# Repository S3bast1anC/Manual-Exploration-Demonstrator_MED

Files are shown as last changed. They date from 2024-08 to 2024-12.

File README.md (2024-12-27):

# Manual-Exploration-Demonstrator_MED
The Manual Exploration Demonstrator (MED) is a rover developed to test hands-on exploration capabilities. Inspiration from Mechanical Sciences’ - [Design and analysis of a six-wheeled companion robot with mechanical obstacle-overcoming adaptivity](https://ms.copernicus.org/articles/12/1115/2021/). This repo provides an overview of MED's design, components, and operational guidelines to facilitate its use and maintenance.

<p align="center">
  
</p>

## About MED
### Motivation
The core design of MED revolves around a six-wheel rover with two independently rotating rear arms. This rover was created for the Mars Habitat at Berkeley (MHAB) software sub-team for autonomous code testing. The rover's modular design allows for future modifications, whether through hardware upgrades or software adjustments. Its six-wheel design allows  navigation across complex terrain, while the rotating rear provide additional mobility for overcoming obstacles.

We aim to share insights and lessons learned from the design, testing, and implementation of the MED rover. We hope that this information will not only assist the MHAB team but also inspire and guide future rover projects.

### Overview
<p align="center">
  
</p>

Development of MED began as part of the Final BLE Vehicle project for the UC Berkeley Summer 2024 DesInv22 class. Over the course of four weeks, myself and Andrew Alatorre engaged in a process of design, testing, iteration, and refinement to bring the rover to its current state.

<div align="center">
<table>
  <tr>
    <td>
      <table>
        <tr>
          <th>Specification</th>
          <th>Details</th>
        </tr>
        <tr>
          <td>Dimension (LxWxH)</td>
          <td>33.81cm x 22.4cm x 10.37cm</td>
        </tr>
        <tr>
          <td>Top Speed</td>
          <td> tbd m/s</td>
        </tr>
        <tr>
          <td>Total Mass</td>
          <td> tbd kg</td>
        </tr>
        <tr>
          <td>Wheel Diameter</td>
          <td> 6.9cm (front/rear), 8.61cm (back) </td>
        </tr>
        <tr>
          <td>Operational Range</td>
          <td> tbd </td>
        </tr>
        <tr>
          <td>Climbing Gradient</td>
          <td> tbd </td>
        </tr>
        <tr>
          <td>Cost</td>
          <td>$90.61</td>
        </tr>
      </table>
    </td>
    <td>
      <a href="https://youtu.be/sea0DLn0pgA" target="_blank">
    Watch the video
</a>
    </td>
  </tr>
</table>
</div>

## Components
### Features

<p align="center">
  
</p>

<ul>
  <li> <b> Six-Wheel Drive: </b> MED is built on a six-wheel drive system, providing improved traction and stability. This configuration ensures balanced weight distribution and allows the rover to handle rough, uneven surfaces with ease.</li>
  <li> <b> Freely Rotating Rear Arms: </b> The two rear arms are capable of rotating freely, giving the rover additional flexibility when navigating obstacles. These arms help stabilize the rover going over inclines and allow for obstacle-overcoming adaptivity in challenging environments.</li>
  <li> <b> Lightweight Build: </b> Constructed from PLA and acrylic, MED’s lightweight chassis allows for easy transportation and reduced energy consumption, while still offering a durable frame for the rover's internal electronics. It was designed this way as an ideal balance between durability and weight, enabling both indoor and outdoor testing.</li>
<li> <b>Rear Storage Compartment:</b> MED includes a simple rear storage compartment, serving as an early look at soil collection concepts. While still remaining simple in design so it can be changed easily." </li>
  
</ul>

### ELECTRONICS
- Arduino Uno Rev3 ([DIGIKEY](https://www.digikey.com/en/products/detail/arduino/A000066/2784006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)) ([DESC](https://store-usa.arduino.cc/products/arduino-uno-rev3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))
- Adafruit Motor Shield V2 ([DIGIKEY](https://www.digikey.com/en/products/detail/adafruit-industries-llc/1438/5353647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)) ([DESC](https://learn.adafruit.com/adafruit-motor-shield-v2-for-arduino/overview))
  - Bluefruit LE UART BT BLE ([DIGIKEY](https://www.digikey.com/en/products/detail/adafruit-industries-llc/2479/5356835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)) ([DESC](https://www.adafruit.com/product/2479))
  - Stacking Headers ([DIGIKEY](https://www.digikey.com/en/products/detail/adafruit-industries-llc/85/5154649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)) ([DESC](https://learn.adafruit.com/adafruit-motor-shield-v2-for-arduino/install-headers))
- 4 DC Gear Motor TT - 120 RPM ([DIGIKEY](https://www.digikey.com/en/products/detail/seeed-technology-co.,-ltd/114090050/10385087?utm_adgroup=&utm_source=google&utm_medium=cpc&utm_campaign=PMax%20Shopping_Product_Low%20ROAS%20Categories&utm_term=&utm_content=&utm_id=go_cmp-20243063506_adg-_ad-__dev-c_ext-_prd-10385087_sig-EAIaIQobChMI8M6mgs6GiAMVdxGtBh0vUSmqEAQYASABEgIGUPD_BwE&gad_source=1&gclid=EAIaIQobChMI8M6mgs6GiAMVdxGtBh0vUSmqEAQYASABEgIGUPD_BwE)) ([DESC](https://grobotronics.com/dc-gear-motor-tt-120-rpm-metal-shaft-blue.html?sl=en))
- 10 AA Batteries (4 for R3 board, 6 for DC motors) ([JACOBS](https://store.jacobshall.org/products/battery-aa?_pos=1&_sid=8ecd7b75d&_ss=r))

### Other Parts
- 3 Radial Ball Bearings (608ZZ) ([DIGIKEY](https://www.digikey.com/en/products/detail/adafruit-industries-llc/1178/5356858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))
- 2 4AA Battery Holder with On/Off Switch ([PARTSEXP](https://www.parts-express.com/4-AA-Battery-Holder-with-On-Off-Switch-140-784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))
- 1 2AA Battery Holder with On/Off Switch ([DIGIKEY](https://www.digikey.com/en/products/detail/sparkfun-electronics/PRT-09925/6161750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))
<p align="center">
  
</p>

### Notes
The V-in on the the adafruit motor shield was busted (i.e it wouldn't power the arduino which is an issue because that's what runs the code) so to solve this issue a 4 battery pack was soddered onto the bottom of the board to power it (it's a 5V board). Also the arduino is a limited edition [Maker Shed Exclusive](https://makezine.com/article/technology/arduino/maker-shed-exclusive-make-special-edition-arduino-unos/) uno board (no particular reason that's just what was lying around).

## Software
### Setup
The software for MED is designed to run on Arduino BLE software and communicates with the rover's motors and sensors via Bluetooth using the Ada_BLE_RC program. Ensure that the following three files are placed inside this folder:
1. Ada_BLE_RC.ino - This is the main Arduino sketch file that contains the code to control the rover.
2. BluefruitConfig.h - This header file includes configuration settings specific to the Adafruit Bluefruit BLE module, such as connection parameters and pin definitions.
3. packetParser.cpp - This C++ file handles the parsing of incoming data packets from the Bluetooth controller, translating them into motor control commands for the rover.

Once you have these files inside the Ada_BLE_RC folder, the entire folder should be uploaded to the Arduino IDE. To ensure the code runs correctly, you need to install the following libraries:
- Adafruit BluefruitLE nRF51 (Includes Adafruit_BLE, Adafruit_BluefruitLE_SPI, Adafruit_BluefruitLE_UART)
- SPI (Built-in with Arduino IDE)
- SoftwareSerial (Built-in with Arduino IDE)

*To change the rpm of the motors go to lines 302-305 (for example 'L_MOTOR1->setSpeed(##);' ).
### Bluetooth
The Bluefruit Connect app by Adafruit allows you to send commands to your rover via Bluetooth using a smartphone. Once the app is installed:
- Enable Bluetooth on your smartphone if it's not already on
- Open the Bluefruit Connect app
- Tap the "Connect" button within the app. It will scan for available Bluetooth devices
- Select your Bluefruit BLE module from the list of available devices (it may be named something like "Bluefruit52" or "UART")
- Once connected, you can access various control options within the app such as Control Pad, Accelerometer, or Color Picker to send commands to the rover


## Parameterized Design Model
This drawing presents the geometric parameter model of MED. The diagram highlights the rover's key coordinate frames, geometric parameters, and critical angles.

<p align="center">
  
</p>

Coordinate Frames:
- O: The global reference frame. This serves as the origin for measuring key lengths and angles for the system's kinematics.

Key Measurements:
- Width (W): Denotes the total width of the rover, measured from the outer edges of the wheels on the left and right sides.
- Length (L): Refers to the overall length of the rover, including the front and rear sections.
- Arm Radius (R): Represents the distance from the centroid of the arms at O<sub>2</sub> to the tip of the rocker arm wheels.
- Arm Wheel Radius (r<sub>0</sub>): Describes the radius of the arm wheels connected to the rocker arms.
- Rear Wheel radius (r<sub>1</sub>): Denotes the radius of the rear wheels of the rover.
  
Angles:
- θ<sub>r</sub>: The right arm swing angle, which defines the rotational displacement of the right rocker arm about its pivot point at O<sub>2</sub>.
- θ<sub>l</sub>: The left arm swing angle, representing the rotational displacement of the left rocker arm about its pivot point at O<sub>1</sub>.
- θ<sub>b</sub>: The rear body rotation angle, indicating the tilt or rotation of the rear section of the rover relative to the global reference frame.

The diagram shows the rover's geometric and kinematic structure, focusing on the relationship between the rocker-bogie arms, wheels, and the main body. The rover is shown with its front and rear sections positioned about the center of mass, labeled as C. The length of the rover, L, is measured between the front and rear wheels, while the width W is measured between the outermost points of the left and right wheels. The rocker arms pivot at origins O<sub>2</sub> and O<sub>1</sub>, and their rotation is described by the swing angles θ<sub>r</sub> and θ<sub>l</sub>. The rotation of the rear section is described by θ<sub>b</sub>. 

The radii R and r<sub>0</sub> describe the size and positioning of the rocker arm wheels, with R being the length from the rocker arm pivot point to the wheel, and r<sub>0</sub> and r<sub>1</sub> defining the sizes of the arm wheels and rear wheels, respectively.

<div align="center">
<table>
  <tr>
    <th>
      <p align="center">
        
      </p>
    </th>
    <th>
      <p align="center">
        
      </p>
    </th>
  </tr>
   <tr>
    <th>
      <p align="center">
        
      </p>
    </th>
    <th>
      <p align="center">
        
      </p>
    </th>
  </tr>
</table>
</div>

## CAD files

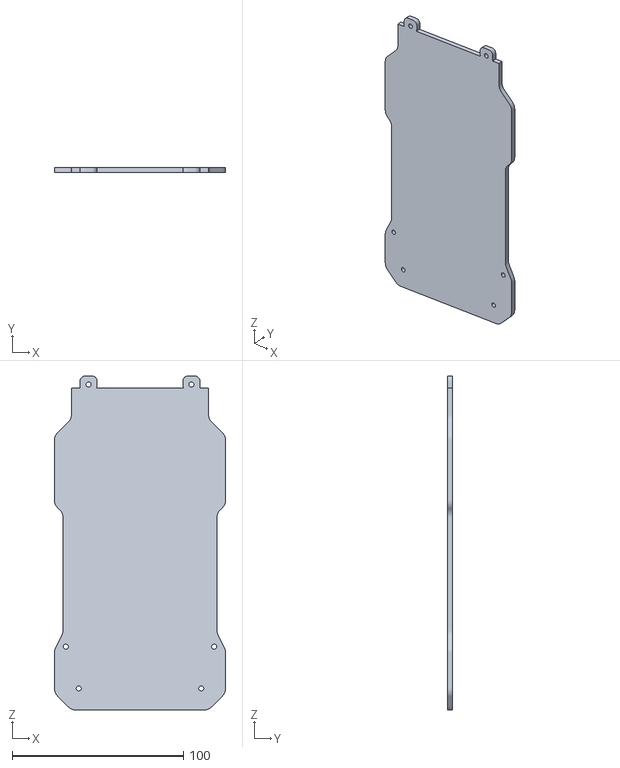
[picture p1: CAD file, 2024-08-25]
STL_Files/Acrylic_Main_Body.stl
100.0 x 3.17 x 195.0

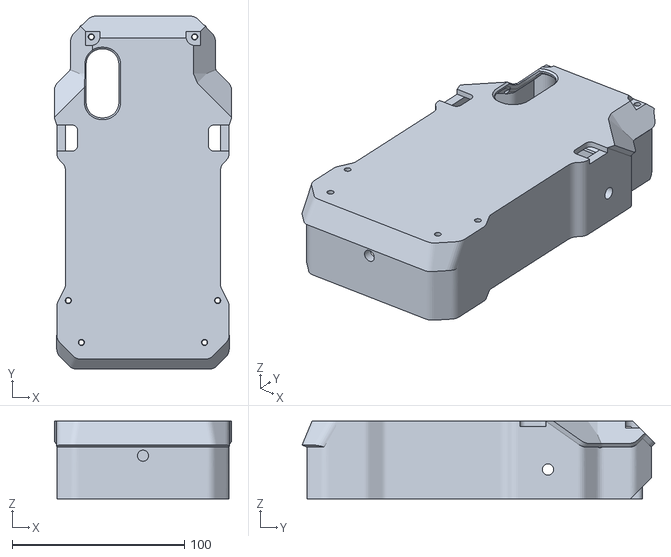
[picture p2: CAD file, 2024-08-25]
STL_Files/Main_Frame (and Lid).stl
103.0 x 204.9 x 45.0

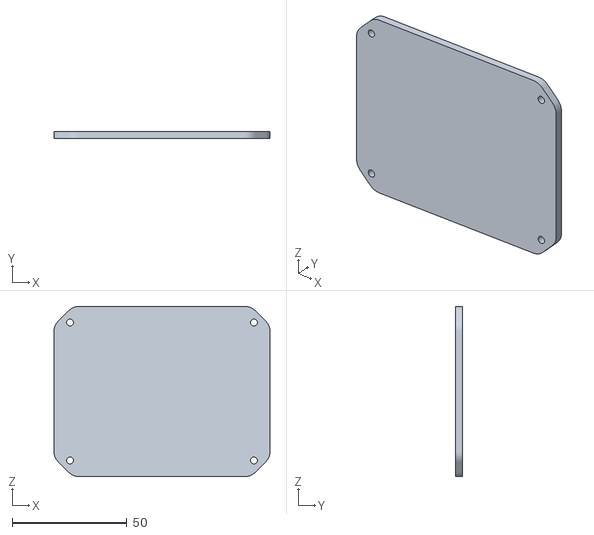
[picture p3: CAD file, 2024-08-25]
STL_Files/Acrylic_Rear_Body.stl
94.0 x 3.17 x 74.0

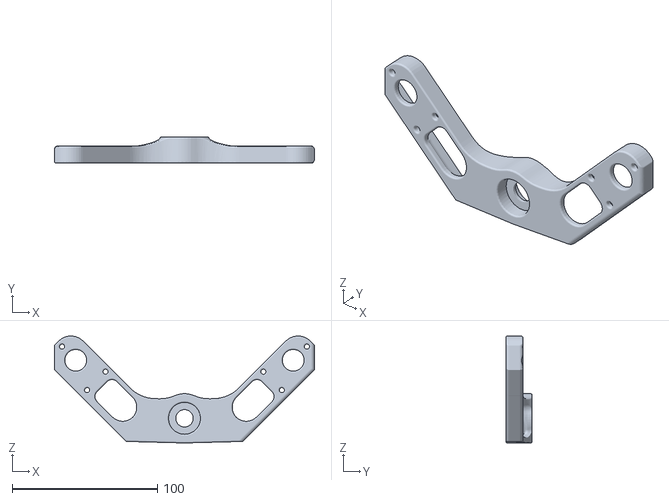
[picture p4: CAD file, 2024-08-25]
STL_Files/Wheel_Rocker_Arms.stl
179.3 x 18.0 x 73.7

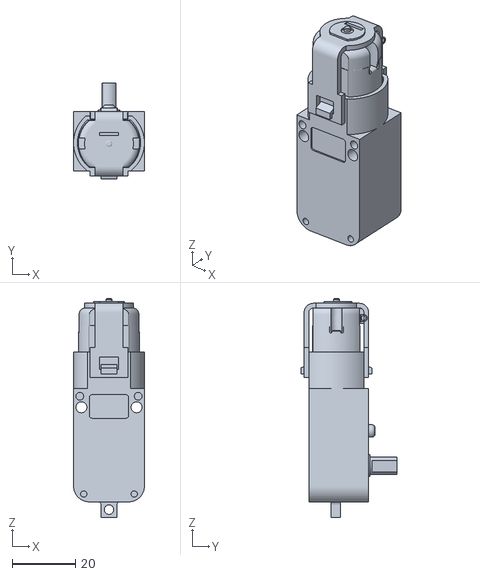
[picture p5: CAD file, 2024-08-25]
STL_Files/Geared_Motor_3-6V.stl
22.5 x 30.5 x 69.5

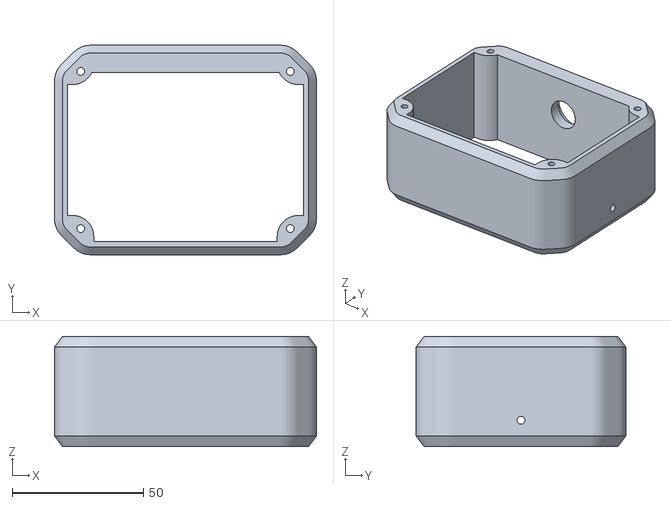
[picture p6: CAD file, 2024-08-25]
STL_Files/Back_Frame.stl
100.0 x 80.0 x 42.0

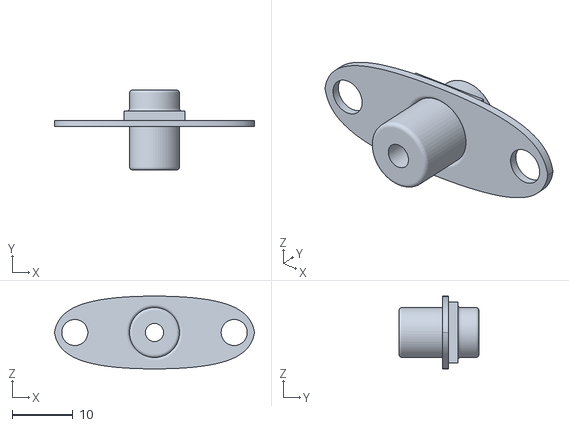
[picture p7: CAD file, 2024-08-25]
STL_Files/Wheel_Hub.stl
33.0 x 13.2 x 12.0

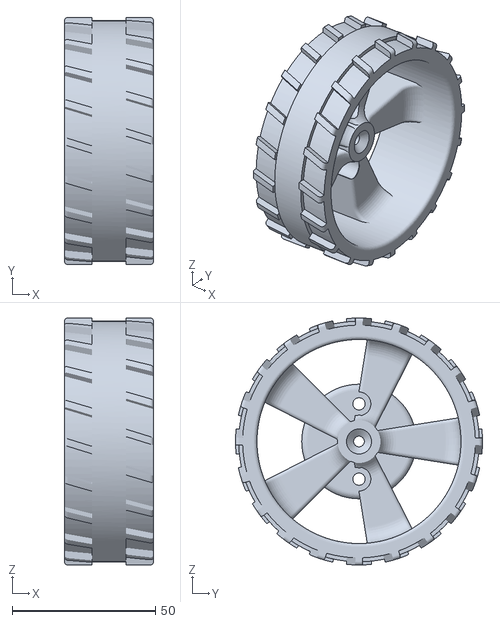
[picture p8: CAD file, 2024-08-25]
STL_Files/Wheel_1.25 (rubberband).stl
31.2 x 86.2 x 86.2

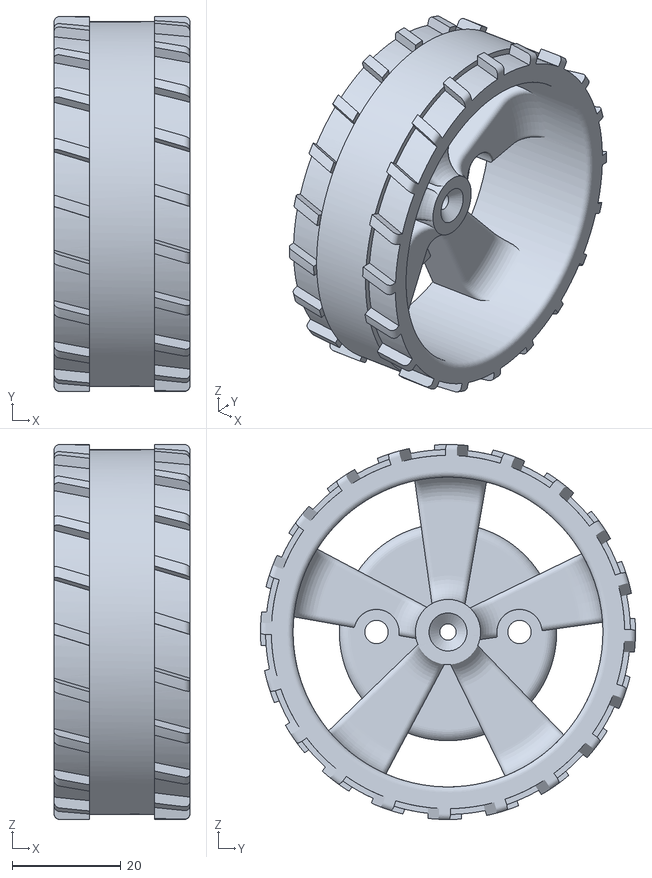
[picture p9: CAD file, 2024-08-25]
STL_Files/Wheel_1.00 (rubberband).stl
25.0 x 69.0 x 69.0

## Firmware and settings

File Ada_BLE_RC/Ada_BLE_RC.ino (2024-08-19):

// SPDX-FileCopyrightText: 2018 Limor Fried for Adafruit Industries
//
// SPDX-License-Identifier: MIT

/*********************************************************************
 This is an example for our nRF51822 based Bluefruit LE modules
  
 Modified to drive a 3-wheeled BLE Robot Rover! by http://james.devi.to
 Pick one up today in the Adafruit shop!
 Adafruit invests time and resources providing this open source code,
 please support Adafruit and open-source hardware by purchasing
 products from Adafruit!
 MIT license, check LICENSE for more information
 All text above, and the splash screen below must be included in
 any redistribution
*********************************************************************/

#include <string.h>
#include <Arduino.h>
#include <SPI.h>
#if not defined (_VARIANT_ARDUINO_DUE_X_)
  #include <SoftwareSerial.h>
#endif

#include "Adafruit_BLE.h"
#include "Adafruit_BluefruitLE_SPI.h"
#include "Adafruit_BluefruitLE_UART.h"

#include "BluefruitConfig.h"

#include <Wire.h>
#include <Adafruit_MotorShield.h>

#define Forward50 50
#define Forward100 100
// #include "utility/Adafruit_PWMServoDriver.h"
// #include <Servo.h> 

// Create the motor shield object with the default I2C address
Adafruit_MotorShield AFMS = Adafruit_MotorShield(); 

// And connect 2 DC motors to port M3 & M4 !
Adafruit_DCMotor *R_MOTOR1 = AFMS.getMotor(1);
Adafruit_DCMotor *R_MOTOR2 = AFMS.getMotor(2);
Adafruit_DCMotor *L_MOTOR1 = AFMS.getMotor(3);
Adafruit_DCMotor *L_MOTOR2 = AFMS.getMotor(4);

//not used, testing acceleration
// int accelTime = 200;

//Name your RC here
String BROADCAST_NAME = "adafruit red robot rover";

String BROADCAST_CMD = String("AT+GAPDEVNAME=" + BROADCAST_NAME);

Adafruit_BluefruitLE_SPI ble(BLUEFRUIT_SPI_CS, BLUEFRUIT_SPI_IRQ, BLUEFRUIT_SPI_RST);


// A small helper
void error(const __FlashStringHelper*err) {
  Serial.println(err);
  while (1);
}

// function prototypes over in packetparser.cpp
uint8_t readPacket(Adafruit_BLE *ble, uint16_t timeout);
float parsefloat(uint8_t *buffer);
void printHex(const uint8_t * data, const uint32_t numBytes);

// the packet buffer
extern uint8_t packetbuffer[];

char buf[60];

/**************************************************************************/
/*!
    @brief  Sets up the HW an the BLE module (this function is called
            automatically on startup)
*/
/**************************************************************************/
void setup(void)
{
  Serial.begin(9600);

  AFMS.begin();  // create with the default frequency 1.6KHz

  // turn on motors
  L_MOTOR1->setSpeed(0);
  L_MOTOR1->run(RELEASE);
  L_MOTOR2->setSpeed(0);
  L_MOTOR2->run(RELEASE);

  R_MOTOR1->setSpeed(0);
  R_MOTOR1->run(RELEASE);
  R_MOTOR2->setSpeed(0);
  R_MOTOR2->run(RELEASE);
    
  Serial.begin(115200);
  Serial.println(F("Adafruit Bluefruit Robot Controller Example"));
  Serial.println(F("-----------------------------------------"));

  /* Initialize the module */
  BLEsetup();
  

}

int velocity = 0;

float x, y;

int L_restrict = 0;
int R_restrict = 0;

unsigned long lastAccelPacket = 0;

bool modeToggle = false;

void loop(void)
{
    // read new packet data
    uint8_t len = readPacket(&ble, BLE_READPACKET_TIMEOUT);
    // if (len == 0) return;

  // Read from Accelerometer input
    if( accelMode() ) {
      lastAccelPacket = millis();
      modeToggle = true;
      return;
    }

  // Stop motors if accelerometer data is turned off (100ms timeout)
    if( millis() - lastAccelPacket > 100 & modeToggle) {
      L_MOTOR1->run(RELEASE);
      L_MOTOR2->run(RELEASE);
      R_MOTOR1->run(RELEASE);
      R_MOTOR2->run(RELEASE);
      modeToggle = false;
      return;
    }

    //if no accelerometer, use control pad
    if( !modeToggle ) buttonMode();
    
}


bool accelMode(){
  if (packetbuffer[1] == 'A') {
          x = parsefloat( packetbuffer + 2 );
          y = parsefloat( packetbuffer + 6 );

        if( x <= -0.55 ){
          x += 0.55;
          x *= -100.0;
          L_MOTOR1->run( BACKWARD );
          L_MOTOR2->run( BACKWARD );
          R_MOTOR1->run( BACKWARD );
          R_MOTOR2->run( BACKWARD );
          if( x >= 45 ) x = 45;
          if( x <= 0 ) x = 0;
          velocity = map( x, 0, 45, 0 ,255 );
        }
        else if( x >= -0.25 ){
          x+= 0.25;
          x *= 100;
          L_MOTOR1->run( FORWARD );
          L_MOTOR2->run( FORWARD );
          R_MOTOR1->run( FORWARD );
          R_MOTOR2->run( FORWARD );
          
          if( x>= 45 ) x = 45;
          if( x<= 0 ) x = 0;
          velocity = map( x, 0, 45, 0, 255 );
        }
        else{
          L_MOTOR1->run( RELEASE );
          L_MOTOR2->run( RELEASE );
          R_MOTOR1->run( RELEASE );
          R_MOTOR2->run( RELEASE );
          velocity = 0;
        }

        //account for L / R accel

        if( y >= 0.1 ){
            y -= 0.1;
            y *= 100;
            if( y >= 50 ) y = 50;
            if( y <= 0 ) y = 0;

            L_restrict = fscale( y, 0.0, 50.0, 0.0, 100.0, -4.0 );
        }
        else if( y <= -0.1 ){
            y += 0.1;
            y *= -100;
            if( y>= 50 ) y = 50;
            if( y<= 0 ) y = 0;

            R_restrict = fscale( y, 0.0, 50.0, 0.0, 100.0, -4.0 );
        }
        else{
            L_restrict = 0;
            R_restrict = 0;
        }

          float Lpercent = ( 100.0 - L_restrict ) / 100.00 ;
          float Rpercent = ( 100.0 - R_restrict ) / 100.00 ;

          // Serial.print( x ); 
          // Serial.print( "\t" ); 
          // Serial.print( Lpercent ); 
          // Serial.print( "\t" ); 
          // Serial.print( velocity ); 
          // Serial.print( "\t" ); 
          // Serial.println( Rpercent ); 

          L_MOTOR1->setSpeed( velocity * Lpercent ); 
          L_MOTOR2->setSpeed( velocity * Lpercent ); 
          R_MOTOR1->setSpeed( velocity * Rpercent ); 
          R_MOTOR2->setSpeed( velocity * Rpercent );
           

          return true;
    }
    return false;
}

bool isMoving = false;

bool buttonMode(){

  static unsigned long lastPress = 0;
  

 // Buttons
  if (packetbuffer[1] == 'B') {

    uint8_t buttnum = packetbuffer[2] - '0';
    boolean pressed = packetbuffer[3] - '0';

    // Serial.println(buttnum);

  Serial.println(isMoving);
    if (pressed) {
      isMoving = true;
      if(buttnum == 5){ //forward
        L_MOTOR1->run(FORWARD);
        L_MOTOR2->run(FORWARD);
        R_MOTOR1->run(FORWARD);
        R_MOTOR2->run(FORWARD);
      }
      if(buttnum == 6){ //backward
        L_MOTOR1->run(BACKWARD);
        L_MOTOR2->run(BACKWARD);
        R_MOTOR1->run(BACKWARD); 
        R_MOTOR2->run(BACKWARD);        
      }
      if(buttnum == 7){ //left
        L_MOTOR1->run(BACKWARD);
        L_MOTOR2->run(BACKWARD);
        R_MOTOR1->run(FORWARD);
        R_MOTOR2->run(FORWARD);
      }
      if(buttnum == 8){ //right
        L_MOTOR1->run(FORWARD);
        L_MOTOR2->run(FORWARD);
        R_MOTOR1->run(BACKWARD);        
        R_MOTOR2->run(BACKWARD);        
      }

      if(buttnum == 1){ //forward-left
        L_MOTOR1->run(Forward50);
        L_MOTOR2->run(Forward50);
        R_MOTOR1->run(FORWARD);        
        R_MOTOR2->run(FORWARD);     
      }

      if(buttnum == 2){ //forward-right
        L_MOTOR1->run(FORWARD);
        L_MOTOR2->run(FORWARD);
        R_MOTOR1->run(RELEASE);        
        R_MOTOR2->run(RELEASE);     
      }

      if(buttnum == 3){ //back-left
        L_MOTOR1->run(RELEASE);
        L_MOTOR2->run(RELEASE);
        R_MOTOR1->run(BACKWARD);        
        R_MOTOR2->run(BACKWARD);     
      }
      
      if(buttnum == 4){ //back-right
        L_MOTOR1->run(BACKWARD);
        L_MOTOR2->run(BACKWARD);
        R_MOTOR1->run(RELEASE);        
        R_MOTOR2->run(RELEASE);     
      }

      lastPress = millis();
      
        L_MOTOR1->setSpeed(230); 
        L_MOTOR2->setSpeed(230); 
        R_MOTOR1->setSpeed(230);  
        R_MOTOR2->setSpeed(230);  
    } 

    else {
      isMoving = false;
      L_MOTOR1->run(RELEASE);
      L_MOTOR2->run(RELEASE);
      R_MOTOR1->run(RELEASE);
      R_MOTOR2->run(RELEASE);
    }
     return true; 
  }
    // if(isMoving){
      
      // unsigned long timeSincePress = millis() - lastPress;

      // if(timeSincePress <= accelTime){

      //   Serial.println( timeSincePress ) ;
        
      //   int motorSpeed = map( timeSincePress, 0, accelTime, 0, 255 );
        
      //   L_MOTOR->setSpeed(motorSpeed); 
      //   R_MOTOR->setSpeed(motorSpeed); 
      // }
      
      // else{
       // // full speed ahead!
        // L_MOTOR->setSpeed(255); 
        // R_MOTOR->setSpeed(255);  
      // }
   // }

  return false;

}

void BLEsetup(){
  Serial.print(F("Initialising the Bluefruit LE module: "));

  if ( !ble.begin(VERBOSE_MODE) )
  {
    error(F("Couldn't find Bluefruit, make sure it's in CoMmanD mode & check wiring?"));
  }
  Serial.println( F("OK!") );

  /* Perform a factory reset to make sure everything is in a known state */
  Serial.println(F("Performing a factory reset: "));
  if (! ble.factoryReset() ){
       error(F("Couldn't factory reset"));
  }

  //Convert the name change command to a char array
  BROADCAST_CMD.toCharArray(buf, 60);

  //Change the broadcast device name here!
  if(ble.sendCommandCheckOK(buf)){
    Serial.println("name changed");
  }
  delay(250);

  //reset to take effect
  if(ble.sendCommandCheckOK("ATZ")){
    Serial.println("resetting");
  }
  delay(250);

  //Confirm name change
  ble.sendCommandCheckOK("AT+GAPDEVNAME");

  /* Disable command echo from Bluefruit */
  ble.echo(false);

  Serial.println("Requesting Bluefruit info:");
  /* Print Bluefruit information */
  ble.info();

  Serial.println(F("Please use Adafruit Bluefruit LE app to connect in Controller mode"));
  Serial.println(F("Then activate/use the sensors, color picker, game controller, etc!"));
  Serial.println();

  ble.verbose(false);  // debug info is a little annoying after this point!

  /* Wait for connection */
  while (! ble.isConnected()) {
      delay(500);
  }

  Serial.println(F("*****************"));

  // Set Bluefruit to DATA mode
  Serial.println( F("Switching to DATA mode!") );
  ble.setMode(BLUEFRUIT_MODE_DATA);

  Serial.println(F("*****************"));
}

//Logarithmic mapping function from http://playground.arduino.cc/Main/Fscale
float fscale( float inputValue,  float originalMin, float originalMax, float newBegin, float newEnd, float curve){

  float OriginalRange = 0;
  float NewRange = 0;
  float zeroRefCurVal = 0;
  float normalizedCurVal = 0;
  float rangedValue = 0;
  boolean invFlag = 0;


  // condition curve parameter
  // limit range

  if (curve > 10) curve = 10;
  if (curve < -10) curve = -10;

  curve = (curve * -.1) ; // - invert and scale - this seems more intuitive - postive numbers give more weight to high end on output 
  curve = pow(10, curve); // convert linear scale into lograthimic exponent for other pow function

  /*
   Serial.println(curve * 100, DEC);   // multply by 100 to preserve resolution  
   Serial.println(); 
   */

  // Check for out of range inputValues
  if (inputValue < originalMin) {
    inputValue = originalMin;
  }
  if (inputValue > originalMax) {
    inputValue = originalMax;
  }

  // Zero Refference the values
  OriginalRange = originalMax - originalMin;

  if (newEnd > newBegin){ 
    NewRange = newEnd - newBegin;
  }
  else
  {
    NewRange = newBegin - newEnd; 
    invFlag = 1;
  }

  zeroRefCurVal = inputValue - originalMin;
  normalizedCurVal  =  zeroRefCurVal / OriginalRange;   // normalize to 0 - 1 float

  /*
  Serial.print(OriginalRange, DEC);  
   Serial.print("   ");  
   Serial.print(NewRange, DEC);  
   Serial.print("   ");  
   Serial.println(zeroRefCurVal, DEC);  
   Serial.println();  
   */

  // Check for originalMin > originalMax  - the math for all other cases i.e. negative numbers seems to work out fine 
  if (originalMin > originalMax ) {
    return 0;
  }

  if (invFlag == 0){
    rangedValue =  (pow(normalizedCurVal, curve) * NewRange) + newBegin;

  }
  else     // invert the ranges
  {   
    rangedValue =  newBegin - (pow(normalizedCurVal, curve) * NewRange); 
  }

  return rangedValue;
}

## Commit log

2024-08-25 Create stl
2024-08-25 Add STL Files for 3D Printing
    [Acrylic_Main_Body.stl, Acrylic_Rear_Body.stl, Back_Frame.stl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]
